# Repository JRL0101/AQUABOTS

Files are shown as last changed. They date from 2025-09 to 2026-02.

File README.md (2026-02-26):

# AQUABOTS — Team 26061

**University of Arizona ENGR 498B — Spring 2026**

Autonomous surface vehicle (ASV) swarm platform.  Three boats operate as a
coordinated swarm using ESP-NOW for inter-node communication.  The leader boat
carries a Jetson Orin Nano, Starlink Mini, and IMX219 camera; follower boats
run a Raspberry Pi + ESP32-S3.

---

## Repository layout

```
AQUABOTS/
├── firmware/          ESP32-S3 swarm logic (ESP-IDF v5.x, FreeRTOS)
│   └── main/          All C source files — see firmware/main/README.md
├── ground_station/    Jetson Orin Nano Python dashboard
│   └── README.md      Setup, config, and data-pipeline docs
├── docs/              Project documents (CDR, ISR, integration plan)
│   └── pics/          Hardware and testing photos
├── reference/         Previous team's CAD files and reference code
└── README.md          This file
```

---

## Hardware overview

| Component | Leader boat | Follower boats |
|---|---|---|
| Compute | Jetson Orin Nano | Raspberry Pi |
| Comms MCU | ESP32-S3 | ESP32-S3 |
| Connectivity | Starlink Mini | — |
| Camera | IMX219 (CSI) | — |
| Obstacle sensor | DFRobot A02YYUW ultrasonic | DFRobot A02YYUW ultrasonic |
| Battery | Ovonic 6S 6000 mAh 22.2V | — |

---

## Subsystems

### `firmware/` — ESP32-S3 swarm firmware

Written in C with ESP-IDF v5.x and FreeRTOS.  All boats run the same binary;
identity is stored in NVS flash.

Key modules:

| Module | Description |
|---|---|
| `node_config` | NVS-backed node identity (node_id 1–254) |
| `swarm_transport` | ESP-NOW send/receive, ping/ack diagnostics |
| `membership` | Peer discovery, heartbeat, active member table |
| `leader_election` | Highest-node-id election with cooldown |
| `scheduler` | TDMA slot coordination (50 ms slots) |
| `command_engine` | Command parsing, routing, and execution |
| `formation` | Line, wedge, circle, column patterns |
| `obstacle_sense` | Pluggable sensor abstraction layer |
| `a02yyuw` | DFRobot A02YYUW UART driver (9600 baud) |
| `avoidance` | State-machine collision avoidance (CLEAR/WARNING/DANGER) |

See `firmware/main/README.md` for build instructions, console commands, and
integration guide.

### `ground_station/` — Jetson Orin Nano dashboard

Python Flask app serving the operator dashboard.  Key components:

| File | Description |
|---|---|
| `app.py` | Flask server — dashboard, `/api/data`, iPerf3 test |
| `serial_bridge.py` | UART bridge: ESP32-S3 → Jetson (IF-3) |
| `mqtt_client.py` | MQTT cloud telemetry via Starlink (IF-4/IF-5) |
| `config.py` | All IPs, ports, and serial settings (env-var overrides) |
| `signaling_server.py` | WebRTC signaling server (WebSocket) |

See `ground_station/README.md` for deployment instructions and environment
variable reference.

---

## Quick start

### Firmware

```bash
cd firmware
idf.py set-target esp32s3
idf.py build
idf.py -p <PORT> flash monitor
```

Provision node identity at the serial console:
```
config set_id <1-254>
```

### Ground station

```bash
cd ground_station
pip install -r requirements.txt
export AQUABOT_SIGNALING_CLIENT_HOST=<jetson-lan-ip>
python app.py           # starts Flask + serial bridge + MQTT
python signaling_server.py   # separate terminal
```

Open `http://<jetson-ip>:5000` in a browser.

---

## Team

| Name | Role |
|---|---|
| John | ESP32-S3 swarm firmware, Power System & Integration |
| Mayra | Ground station dashboard |
| Jamie | Water quality sensors (pH, salinity, temperature) |
| Robert | Propulsion / ESC hardware |

---

## Interfaces (from Software Integration Plan)

| ID | Description | Status |
|---|---|---|
| IF-1 | ESP32-S3 ↔ Pixhawk (MAVLink UART) | Pending |
| IF-3 | ESP32-S3 ↔ Jetson (sensor UART) | Wired, driver ready |
| IF-4/5 | Jetson ↔ Cloud (MQTT via Starlink) | Client ready, broker TBD |
| IF-6 | ESP32-S3 ↔ ESP32-S3 (ESP-NOW) | Complete |

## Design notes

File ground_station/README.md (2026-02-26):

# AquaBot Ground Station

Python/JavaScript web dashboard running on the **Jetson Orin Nano** aboard the
leader boat.  Provides the operator with a live video feed, real-time sensor
readings, swarm telemetry, and network performance metrics over Starlink.

---

## Directory layout

```
ground_station/
├── app.py                 Flask web server (port 5000)
├── signaling_server.py    WebRTC signaling server (WebSocket, port 8765)
├── serial_bridge.py       UART bridge — ESP32-S3 ↔ Jetson (IF-3)
├── mqtt_client.py         MQTT cloud telemetry via Starlink (IF-4 / IF-5)
├── config.py              Centralized configuration (IPs, ports, serial)
├── requirements.txt       Python dependencies
├── static/
│   ├── css/style.css
│   └── js/
│       ├── webrtc.js      WebRTC client (video receive + zoom/record cmds)
│       ├── telemetry.js   Polls /api/data every 2 s, updates dashboard
│       ├── bandwidth.js   iPerf3 network test trigger
│       └── controls.js    (reserved)
└── templates/
    └── index.html         Operator dashboard
```

---

## Quick start

### 1 — Install dependencies

```bash
cd ground_station
pip install -r requirements.txt
```

`iperf3` must also be installed on the Jetson:
```bash
sudo apt install iperf3
```

### 2 — Set environment variables

All IPs and ports are configurable without editing code.  Set the variables
that differ from the defaults below before launching.

| Variable | Default | Description |
|---|---|---|
| `AQUABOT_SIGNALING_CLIENT_HOST` | `localhost` | Jetson LAN IP seen by the browser (e.g. `192.168.1.187`) |
| `AQUABOT_SIGNALING_HOST` | `0.0.0.0` | Address the signaling server binds to |
| `AQUABOT_SIGNALING_PORT` | `8765` | WebSocket port for signaling |
| `AQUABOT_IPERF_HOST` | `192.168.1.77` | iPerf3 server IP |
| `AQUABOT_IPERF_PORT` | `5201` | iPerf3 port |
| `AQUABOT_FLASK_HOST` | `0.0.0.0` | Flask bind address |
| `AQUABOT_FLASK_PORT` | `5000` | Flask port |
| `AQUABOT_SERIAL_PORT` | `/dev/ttyUSB0` | ESP32-S3 serial device |
| `AQUABOT_SERIAL_BAUD` | `115200` | Serial baud rate |
| `AQUABOT_MQTT_BROKER` | `broker.hivemq.com` | MQTT broker hostname |
| `AQUABOT_MQTT_PORT` | `1883` | MQTT broker port |
| `AQUABOT_MQTT_USER` | *(empty)* | MQTT username (if required) |
| `AQUABOT_MQTT_PASS` | *(empty)* | MQTT password (if required) |
| `AQUABOT_NODE_ID` | `leader` | Node identifier for MQTT topics |

Example for deployment on the Jetson:
```bash
export AQUABOT_SIGNALING_CLIENT_HOST=192.168.1.187
export AQUABOT_SERIAL_PORT=/dev/ttyUSB0
```

### 3 — Launch the Flask dashboard (starts serial bridge + MQTT automatically)

```bash
python app.py
```

Open `http://<jetson-ip>:5000` in a browser.

### 4 — Launch the WebRTC signaling server (separate terminal)

```bash
python signaling_server.py
```

The IMX219 camera stream is sent to the signaling server by a GStreamer
pipeline on the Jetson; the browser receives it via WebRTC.

---

## Interface diagram

```
ESP32-S3 (swarm node)
    │  UART 115200 baud (IF-3)
    ▼
serial_bridge.py  ──────────► shared state dict (thread-safe)
                                    │                │
                              Flask /api/data    mqtt_client.py
                                    │                │
                              telemetry.js       Starlink Mini
                              (browser, 2 s)     (IF-4 / IF-5)
                                                      │
                                               cloud MQTT broker
```

---

## Data pipeline — sensor readings

1. **Jamie's sensors** (pH, salinity, temperature) connect to the ESP32-S3.
2. The ESP32-S3 sends newline-delimited JSON over UART:
   ```json
   {"type":"sensor","node_id":1,"ph":7.2,"salinity":35.1,"temp_c":22.5}
   ```
3. `serial_bridge.py` parses the frame and updates the shared state dict.
4. `app.py /api/data` serves the state as JSON.
5. `telemetry.js` polls `/api/data` every 2 seconds and updates the DOM.

The same pipeline carries swarm telemetry and obstacle/avoidance state.

---

## MQTT topic layout

| Topic | Direction | Payload |
|---|---|---|
| `aquabots/<node_id>/sensor` | publish | pH, salinity, temp_c |
| `aquabots/<node_id>/telemetry` | publish | heading, leader_id, formation |
| `aquabots/<node_id>/obstacle` | publish | avoidance state, range |
| `aquabots/swarm/status` | publish | combined heartbeat |
| `aquabots/command/+` | subscribe | operator commands from cloud |

---

## Pending integration items

- **ESP32-S3 TX path** — `serial_bridge.py` currently only reads; outbound
  command forwarding (Jetson → ESP32-S3) will be added when IF-3 wiring is
  complete.
- **MQTT TLS** — for production, set broker to an AWS IoT Core endpoint and
  configure TLS certificates via environment variables.
- **Mayra's signaling server** currently broadcasts WebRTC to all connected
  clients.  If security is needed, add session tokens.

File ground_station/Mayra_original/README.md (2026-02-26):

# Mayra's Original Dashboard Code

This contains an exact, unmodified copy of your dashboard code.  Nothing here has been changed.

The working version of the dashboard is one level up in `ground_station/`.
That version has been extended to connect to the ESP32-S3 sensor pipeline and
the MQTT cloud uplink, but your logic, structure, and UI are untouched.

## What changed in the integrated version (ground_station/)

| File | What changed |
|---|---|
| `app.py` | Added `/api/data` endpoint; imports `config.py`, `serial_bridge.py`, `mqtt_client.py`; hardcoded IPs moved to `config.py` |
| `signaling_server.py` | Bind address/port read from `config.py` instead of hardcoded |
| `templates/index.html` | Added `id=` attributes to sensor/swarm fields so `telemetry.js` can populate them; added Swarm Status panel; loads `telemetry.js`; signaling URL injected by Flask |
| `static/js/webrtc.js` | Reads signaling server URL from `window.AQUABOT_SIGNALING_URL` (set by Flask template) instead of hardcoded `192.168.1.187` |

## New files added

| File | Purpose |
|---|---|
| `config.py` | All IPs, ports, and serial settings in one place; all overridable via environment variables |
| `serial_bridge.py` | Reads sensor/telemetry data from ESP32-S3 over UART |
| `mqtt_client.py` | Publishes telemetry to cloud via Starlink MQTT |
| `static/js/telemetry.js` | Polls `/api/data` every 2 s and updates the sensor/swarm fields in the dashboard |
| `requirements.txt` | Python dependencies |

## Files not changed at all

- `static/css/style.css`
- `static/js/bandwidth.js`
- `static/js/controls.js`

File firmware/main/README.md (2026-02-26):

# AQUABOTS — ESP32-S3 Swarm Framework

**Platform:** ESP32-S3 with ESP-IDF v5.5.x
**Protocol:** ESP-NOW (2.4 GHz, channel 1)
**Target:** 20–50 node autonomous surface vehicle swarm

---

## Table of Contents

1. [Overview](#overview)
2. [System Architecture](#system-architecture)
3. [Module Reference](#module-reference)
4. [Hardware Setup](#hardware-setup)
5. [Building and Flashing](#building-and-flashing)
6. [Node Provisioning](#node-provisioning)
7. [Console Command Reference](#console-command-reference)
8. [Integration Guide](#integration-guide)
9. [Testing and Verification](#testing-and-verification)
10. [Troubleshooting](#troubleshooting)
11. [Performance Reference](#performance-reference)

---

## Overview

AQUABOTS is a distributed swarm coordination framework for ESP32-S3 microcontrollers
targeting autonomous surface vehicles (ASVs). All coordination is done peer-to-peer
over ESP-NOW — no router, broker, or infrastructure is required.

### Capabilities

- **Zero-configuration networking** — nodes discover each other automatically via broadcast
- **Persistent identity** — each node has a unique ID stored in flash that survives power cycles
- **Distributed leader election** — highest node_id automatically becomes the swarm leader
- **Time-slotted communication** — TDMA scheduling prevents radio collisions at scale
- **Synchronized command execution** — the leader sends GOTO/HOLD/STOP/RESUME to the entire swarm
- **Formation control** — four built-in patterns (line, wedge, circle, column) with configurable spacing
- **Obstacle sensing** — pluggable sensor driver system with swarm-wide scan fusion
- **Collision avoidance** — autonomous safety zones with automatic stop and alternate-path suggestion
- **Resilient design** — automatic leader failover if the current leader goes offline

### Technology Stack

| Component | Technology |
|---|---|
| Hardware | ESP32-S3 (Xtensa dual-core @ 240 MHz) |
| Framework | ESP-IDF v5.5.x |
| RTOS | FreeRTOS |
| Radio | ESP-NOW (2.4 GHz) |
| Storage | NVS (Non-Volatile Storage) |
| Console | USB Serial/JTAG |

---

## System Architecture

```
┌──────────────────────────────────────────────────────────────┐
│                       APPLICATION LAYER                       │
├────────────────────┬─────────────────────┬───────────────────┤
│  Formation Control │   Command Engine    │ Collision Avoid   │
├────────────────────┴──────┬──────────────┴───────────────────┤
│     Leader Election       │    Obstacle Sensing + Fusion      │
├───────────────────────────┴───────────────────────────────────┤
│                  Membership Discovery                          │
├───────────────────────────────────────────────────────────────┤
│           Node Configuration (NVS identity)                   │
├───────────────────────────────────────────────────────────────┤
│              Swarm Transport (ESP-NOW)                         │
└───────────────────────────────────────────────────────────────┘
```

### Data Flow

```
Physical sensor (A02YYUW)
        │  UART 9600 baud
        ▼
   a02yyuw driver ──► obstacle_sense (local scan, 10 Hz)
                              │
                              ├──► broadcast to swarm (2 Hz, MSG_TYPE_OBSTACLE)
                              │
                              ├──► receives remote scans from peers
                              │
                              └──► avoidance (polls every 250 ms)
                                        │
                                  DANGER zone ──► CMD_STOP (leader only)
                                  CLEAR found ──► suggest alternate bearing
```

---

## Module Reference

### swarm_transport (`swarm_transport.h / .c`)

ESP-NOW radio abstraction layer. Manages peer registration, send/receive dispatch,
and supports multiple simultaneous receive callbacks via a callback table.

- **Channel:** 1 (configurable via `TRANSPORT_CHANNEL`)
- **Max peers:** 20 (configurable via `TRANSPORT_MAX_PEERS`)
- **Receive dispatch:** up to 8 callbacks registered simultaneously

---

### node_config (`node_config.h / .c`)

Persistent node identity backed by NVS flash. Provides a serial provisioning
console so a single firmware binary can be flashed to every node; each board
is then assigned its unique node_id via `set_node_id`.

- **Valid node_id range:** 1–254
- **Storage:** NVS namespace `node_cfg`, key `node_id`
- **Console commands:** `set_node_id`, `get_node_id`, `info`, `help`

---

### membership (`membership.h / .c`)

Zero-configuration peer discovery. Each provisioned node broadcasts a HELLO
packet every 2 seconds. Nodes that stop broadcasting are removed from the
member table after a 10-second timeout.

- **HELLO interval:** 2 000 ms
- **Peer timeout:** 10 000 ms
- **Max peers:** 50 (configurable via `SWARM_MAX_NODES` in `swarm_protocol.h`)
- **Message:** `MSG_TYPE_HELLO` (0x02)

---

### leader_election (`leader_election.h / .c`)

Distributed leader election by highest node_id. The elected leader generates
a TDMA slot schedule and broadcasts it in beacon packets every second. All
nodes receive the beacon and update their slot timing accordingly.

- **Election rule:** highest node_id among all known members
- **Election trigger:** every 5 seconds, or when membership changes
- **TDMA slot duration:** 50 ms per node
- **Beacon interval:** 1 000 ms
- **Message:** `MSG_TYPE_BEACON` (0x03)

**Example schedule (2 nodes, IDs 1 and 2):**
```
Slot 0 (  0– 50 ms): Node 2 (leader)
Slot 1 ( 50–100 ms): Node 1
[cycle repeats every 100 ms]
```

---

### command_engine (`command_engine.h / .c`)

Swarm command distribution. Only the leader can originate commands; followers
receive and execute them. All nodes track execution state independently.
Duplicate detection (via 32-bit command ID) prevents re-execution of
retransmitted packets.

- **Commands:** `GOTO`, `HOLD`, `STOP`, `RESUME`
- **Message:** `MSG_TYPE_COMMAND` (0x04)
- **Thread-safe:** mutex-protected state machine

| Command | Parameters | Behaviour |
|---|---|---|
| GOTO | x, y, heading | Navigate swarm to waypoint |
| HOLD | — | Maintain current position |
| STOP | — | Emergency stop (motors off) |
| RESUME | — | Resume last active command |

---

### formation (`formation.h / .c`)

Coordinated spatial formations. The leader calculates relative position offsets
for each node and broadcasts the formation plan. Each node receives its assigned
offset and applies it to the shared formation centre to obtain its world position.

New patterns can be added without modifying existing code by calling
`formation_register_pattern()` with a custom calculator function.

- **Built-in patterns:** line, wedge, circle, column
- **Default spacing:** 2 000 mm (configurable 500–10 000 mm)
- **Message:** `MSG_TYPE_FORMATION` (0x05)

| Pattern | Description |
|---|---|
| `line` | Single file, leader at front |
| `wedge` | V-shape with leader at the point |
| `circle` | Nodes evenly spaced on a ring |
| `column` | Side-by-side parallel columns |

---

### obstacle_sense (`obstacle_sense.h / .c`)

Sensor abstraction with swarm-wide scan fusion. A pluggable `sensor_driver_fn`
is called at 10 Hz to collect local detections. The local scan is broadcast at
2 Hz to all peers. Remote scans from other nodes are stored and automatically
expired after 2 seconds if not refreshed.

All query APIs (`obstacle_sense_get_closest`, `obstacle_sense_path_clear`,
`obstacle_sense_get_all_scans`) operate across both local and all current remote
scans, giving every node a unified obstacle picture of the entire swarm's field
of view.

**Mock mode** is active by default. It allows full swarm testing without any
physical sensors attached. Use `mock_add` to inject test obstacles from the
console.

- **Local scan rate:** 10 Hz (100 ms interval)
- **Broadcast rate:** 2 Hz (500 ms interval)
- **Scan timeout:** 2 000 ms
- **Max tracked nodes:** 16
- **Max detections per scan:** 16
- **Message:** `MSG_TYPE_OBSTACLE` (0x07)

**Obstacle protocol frame:**
```
Header (16 bytes):
  uint16  source_node_id
  uint8   num_detections
  uint8   sensor_id
  uint32  timestamp_ms
  uint32  scan_seq
  int16   range_max_mm
  int16   fov_deg

Per detection (8 bytes each):
  int16   range_mm
  int16   bearing_deg
  int16   velocity_mms
  uint8   confidence
  uint8   object_type
```

**Object types:**

| Value | Name | Description |
|---|---|---|
| 0 | UNKNOWN | Unclassified detection |
| 1 | STATIC | Stationary object |
| 2 | MOVING | Moving object (has velocity) |
| 3 | BOAT | Another vessel |
| 4 | SHORE | Shoreline or land mass |
| 5 | DEBRIS | Floating debris |

---

### a02yyuw (`a02yyuw.h / .c`)

UART driver for the **DFRobot A02YYUW** waterproof ultrasonic distance sensor.

The A02YYUW measures range in one fixed direction using a simple 4-byte UART
protocol. Since the sensor has no angular output, each instance is configured
with a `mounting_angle_deg` that describes which direction it faces on the hull.
Up to four sensor instances can be active simultaneously at different mounting
angles to achieve multi-directional coverage.

The driver exposes `a02yyuw_scan_driver()` which is a drop-in `sensor_driver_fn`
for `obstacle_sense_register_driver()`.

**Sensor specifications:**

| Parameter | Value |
|---|---|
| Interface | UART, 9600 baud |
| Supply voltage | 3.3 V or 5 V |
| Current draw | ~40 mA |
| Detection range | 30 mm – 4 500 mm |
| Update rate | ~10 Hz |
| Waterproof rating | IP67 |
| Angular output | None (point sensor) |

**Frame format (4 bytes):**
```
Byte 0: 0xFF        (header)
Byte 1: DATA_H      (distance high byte)
Byte 2: DATA_L      (distance low byte)
Byte 3: SUM         (checksum = (0xFF + DATA_H + DATA_L) & 0xFF)

Distance (mm) = DATA_H * 256 + DATA_L
Valid range: 30 to 4500 mm
```

**Wiring:**

| Wire colour | Connect to |
|---|---|
| Red | 3.3 V or 5 V |
| Black | GND |
| Blue | ESP32 UART RX pin (sensor TX) |
| Green | ESP32 UART TX pin (sensor RX) — usually unused |

**Multi-sensor layout for 360° coverage:**
```
            BOW (0°)
              [S0]
               ↑
               │
  [S3] (-90°)──┼──(+90°) [S1]
               │
               ↓
              [S2]
           STERN (180°)

S0: UART_NUM_1, RX=GPIO17, angle=   0° (bow)
S1: UART_NUM_2, RX=GPIO18, angle= +90° (starboard)
S2: requires additional UART,  angle= 180° (stern)
S3: requires additional UART,  angle= -90° (port)
```

**Activating the hardware driver:**

In `main.c`, uncomment the sensor block before `obstacle_sense_start()`:

```c
#include "a02yyuw.h"

// Initialize sensors (call before obstacle_sense_start)
a02yyuw_init(0, UART_NUM_1, GPIO_NUM_17, -1, 0);   // Bow sensor
a02yyuw_init(1, UART_NUM_2, GPIO_NUM_18, -1, 90);  // Starboard sensor

// Register with obstacle_sense (replaces mock driver)
obstacle_sense_register_driver(a02yyuw_scan_driver);
obstacle_sense_configure(4500, 120);  // 4.5 m range, 120° FOV per sensor
```

---

### avoidance (`avoidance.h / .c`)

Collision avoidance policy engine. Runs a 250 ms check loop that queries the
fused obstacle picture from `obstacle_sense` and transitions through a three-level
state machine:

```
DISABLED → CLEAR → WARNING → DANGER
               ↑_______________|
```

| State | Condition | Action |
|---|---|---|
| CLEAR | No obstacle within `warning_mm` | None |
| WARNING | Obstacle < `warning_mm` | Fire state callback; log alert |
| DANGER | Obstacle < `danger_mm` | Fire callback; auto-stop (leader); suggest alternate bearing |

When entering DANGER, the engine searches 8 candidate bearings
(0°, ±45°, ±90°, ±135°, 180°) for the first one that is clear within
`warning_mm`. The result is reported via the `avoidance_suggest_cb_t` callback.

Auto-stop only executes when `auto_stop = true` **and** this node is the swarm
leader, keeping the entire swarm synchronized rather than having individual nodes
act independently.

**Default thresholds:**

| Parameter | Default | Description |
|---|---|---|
| `danger_mm` | 500 mm | Obstacle closer than this triggers DANGER |
| `warning_mm` | 1 500 mm | Obstacle closer than this triggers WARNING |
| `corridor_deg` | 40° | Path-check corridor total width (±20°) |
| `auto_stop` | true | Issue CMD_STOP when entering DANGER |

---

## Hardware Setup

### Minimum (mock sensor mode)

- 2× ESP32-S3 development boards
- USB cables for serial console and flashing

No physical distance sensors are required. The mock driver in `obstacle_sense`
lets you simulate obstacles via console commands for full swarm testing.

### With A02YYUW Sensors

**Single forward-facing sensor:**

```
ESP32-S3                  A02YYUW
──────────                ───────
3.3V or 5V ──────────────  Red
GND        ──────────────  Black
GPIO17 (RX)──────────────  Blue (sensor TX)
(TX unused)
```

**Dual sensor (bow + starboard):**

```
ESP32-S3     Sensor 0 (bow)   Sensor 1 (starboard)
3.3V     ──► Red              Red
GND      ──► Black            Black
GPIO17   ──► Blue             —
GPIO18   ──────────────────►  Blue
```

> **Note:** The ESP32-S3 has three hardware UART peripherals (UART0, UART1, UART2).
> UART0 is normally used by the serial console, leaving UART1 and UART2 for sensors.
> For more than two sensors, consider an external UART multiplexer.

---

## Building and Flashing

### Prerequisites

- ESP-IDF v5.5.x ([installation guide](https://docs.espressif.com/projects/esp-idf/en/latest/esp32s3/get-started/))
- Two or more ESP32-S3 development boards
- USB cables

### Build

```bash
cd swarmLogic

# Build firmware (single binary for all nodes)
idf.py build
```

### Flash

```bash
# Flash Node 1 (adjust COM port as needed)
idf.py -p COM9 flash monitor

# In the serial console:
swarm> set_node_id 1
# Press Ctrl+T, Ctrl+R to restart

# Flash Node 2
idf.py -p COM7 flash monitor

swarm> set_node_id 2
# Press Ctrl+T, Ctrl+R to restart
```

### Expected Boot Output

```
I (442) MAIN: ================================================
I (442) MAIN:  AQUABOTS — ESP32-S3 Swarm Framework
I (442) MAIN: ================================================
I (442) MAIN: Node ID : 2
I (442) MAIN: MAC     : 10:b4:1d:d0:a5:f4
I (452) MEMBERSHIP: HELLO broadcast task started
I (452) LEADER_ELECTION: Leader election task started
I (452) COMMAND_ENGINE: Command engine started
I (452) FORMATION: Formation control started
I (452) OBSTACLE_SENSE: Scan task started (interval=100 ms)
I (452) OBSTACLE_SENSE: Broadcast task started (interval=500 ms)
I (452) AVOIDANCE: Avoidance started
I (1052) MAIN: *** NEW MEMBER DISCOVERED ***
I (1052) MAIN:     Node ID: 1
I (1072) MAIN: *** NEW LEADER ELECTED ***
I (1072) MAIN:     Leader Node ID: 2
```

---

## Node Provisioning

Each board must be assigned a unique node_id before it can participate in the
swarm. Node IDs persist through firmware updates and power cycles.

```bash
# Check current node_id
swarm> get_node_id

# Assign a node_id (1–254)
swarm> set_node_id 3

# Restart to activate
[Ctrl+T, Ctrl+R]

# Verify
swarm> info
```

**Rules:**
- Valid range: 1–254
- Higher node_id = leader (deterministic, no election messages needed)
- Each node in the swarm must have a unique ID
- ID 0 and 255 are reserved

---

## Console Command Reference

### Node and Network Status

| Command | Description |
|---|---|
| `help` | List all available commands |
| `info` | Show node_id, MAC, and provisioning status |
| `get_node_id` | Display current node_id |
| `set_node_id <id>` | Assign node_id 1–254 (requires restart) |
| `members` | Show discovered swarm members with RSSI |
| `leader` | Show current leader and election state |
| `schedule` | Show TDMA slot schedule |
| `status` | Show current command execution state |

### Swarm Commands *(leader only)*

| Command | Description | Example |
|---|---|---|
| `goto <x> <y> [heading]` | Navigate swarm to waypoint (metres) | `goto 10 20 90` |
| `hold` | Hold current position | `hold` |
| `stop` | Emergency stop (motors off) | `stop` |
| `resume` | Resume last command | `resume` |

### Formation Control *(leader only)*

| Command | Description | Example |
|---|---|---|
| `formation <type>` | Set formation pattern | `formation wedge` |
| `spacing <mm>` | Set inter-node spacing in mm | `spacing 3000` |
| `fmove <dx> <dy>` | Translate entire formation (mm) | `fmove 1000 500` |
| `fstatus` | Show formation type and node assignments | `fstatus` |

Formation types: `line` `wedge` `circle` `column`

### Obstacle Sensing

| Command | Description | Example |
|---|---|---|
| `sensors` | Show sensor driver status and scan counters | `sensors` |
| `detections` | Show all local and remote obstacle detections | `detections` |
| `mock_add <range_mm> <bearing_deg>` | Inject a mock obstacle | `mock_add 2000 0` |
| `mock_clear` | Remove all mock obstacles | `mock_clear` |
| `path_check <bearing> [corridor] [range]` | Check if a heading is clear | `path_check 0` |

`path_check` defaults: corridor = 30°, range = 3 000 mm

### Collision Avoidance

| Command | Description | Example |
|---|---|---|
| `avoid_status` | Show avoidance state and current thresholds | `avoid_status` |
| `avoid_enable` | Enable the avoidance engine | `avoid_enable` |
| `avoid_disable` | Disable the avoidance engine | `avoid_disable` |
| `avoid_config <param> <value>` | Tune a threshold at runtime | `avoid_config danger_mm 400` |

`avoid_config` parameters: `danger_mm` `warning_mm` `corridor_deg` `auto_stop`

---

## Integration Guide

### Registering a Real Sensor

To replace mock mode with the A02YYUW hardware driver, add the following block
to `main.c` **before** the call to `obstacle_sense_start()`:

```c
#include "a02yyuw.h"

// One sensor, facing forward (0°), on UART1, RX = GPIO17
a02yyuw_init(0, UART_NUM_1, GPIO_NUM_17, -1, 0);

// Replace mock driver with the hardware driver
obstacle_sense_register_driver(a02yyuw_scan_driver);

// Optional: match sensor spec (4.5 m range, 120° FOV)
obstacle_sense_configure(4500, 120);
```

### Implementing a Custom Sensor Driver

Any sensor that can produce range/bearing measurements can be used. Implement
the `sensor_driver_fn` signature and register it:

```c
bool my_sensor_driver(obstacle_scan_t *scan)
{
    // Read from hardware
    int16_t range_mm = my_sensor_read();
    if (range_mm <= 0) {
        scan->num_detections = 0;
        return true;  // Empty scan is valid
    }

    scan->num_detections = 1;
    scan->detections[0].range_mm     = range_mm;
    scan->detections[0].bearing_deg  = 0;      // Sensor faces forward
    scan->detections[0].velocity_mms = 0;
    scan->detections[0].confidence   = 85;
    scan->detections[0].object_type  = OBSTACLE_TYPE_UNKNOWN;
    return true;
}

// Register before obstacle_sense_start()
obstacle_sense_register_driver(my_sensor_driver);
```

### Adding a Formation Pattern

```c
// 1. Add enum value in formation.h
typedef enum {
    FORMATION_NONE = 0,
    FORMATION_LINE,
    FORMATION_WEDGE,
    FORMATION_CIRCLE,
    FORMATION_COLUMN,
    FORMATION_DIAMOND,   // ← new pattern
    FORMATION_COUNT
} formation_type_t;

// 2. Implement calculator function
bool diamond_calc(int node_index, int total_nodes,
                  int32_t spacing_mm, formation_position_t *pos)
{
    // Assign positions for diamond arrangement
    // ...
    return true;
}

// 3. Register in formation_init() inside formation.c
formation_register_pattern(FORMATION_DIAMOND, "diamond", diamond_calc);
```

### Avoidance Callbacks

```c
void my_state_cb(avoidance_state_t state, const obstacle_detection_t *closest)
{
    if (state == AVOIDANCE_STATE_DANGER && closest) {
        // Log to mission computer, light warning LED, etc.
    }
}

void my_suggest_cb(int16_t bearing_deg, int16_t range_clear_mm)
{
    // Could feed this bearing into a higher-level autopilot
    printf("Suggested heading: %d°\n", bearing_deg);
}

// Register before avoidance_start()
avoidance_register_state_cb(my_state_cb);
avoidance_register_suggest_cb(my_suggest_cb);
```

---

## Testing and Verification

### Basic Connectivity

```bash
# On both nodes
swarm> info
# Should show provisioned node_id and MAC

swarm> members
# Should show 1 peer after ~2 seconds
```

### Leader Election

```bash
# On both nodes
swarm> leader
# Node with higher node_id should show "I am leader: YES"
# Lower node_id shows "I am leader: NO"
```

### Command Distribution

```bash
# On the LEADER node only
swarm> goto 100 200 90
# Both nodes should log "*** COMMAND RECEIVED ***"

swarm> status
# Both nodes should show "Command: GOTO, Status: EXECUTING"
```

### Formation Control

```bash
# On the LEADER node
swarm> formation line
# Both nodes should log "*** FORMATION CHANGED ***" and "*** POSITION ASSIGNED ***"

swarm> fstatus
# Shows current formation type and each node's assigned offset
```

### Obstacle Sensing

```bash
# On any node
swarm> sensors
# Should show: Running: YES, Mock mode: ENABLED

# Add mock obstacles
swarm> mock_add 2000 0      # 2 m straight ahead
swarm> mock_add 1500 45     # 1.5 m at 45°
swarm> mock_add 3000 -30    # 3 m at -30°

# Verify local detections
swarm> detections
# Shows 3 obstacles with range/bearing/type

# On the OTHER node — verify remote reception
swarm> detections
# Shows obstacles from the first node as "(remote)"

# Test path clearance
swarm> path_check 0
# Expected: "BLOCKED" (obstacle at 2000 mm @ 0°)

swarm> path_check 90
# Expected: "CLEAR" (no obstacles near 90°)

# Clean up
swarm> mock_clear
swarm> detections
# Expected: no detections
```

### Collision Avoidance

```bash
swarm> avoid_status
# Shows: State: CLEAR, thresholds, auto-stop setting

# Trigger a danger condition with a mock obstacle
swarm> mock_add 400 0       # 40 cm directly ahead (< 500 mm danger zone)

# Watch logs for:
# W AVOIDANCE: DANGER: 400 mm @ 0° (node X)
# W AVOIDANCE: Auto-stop issued to swarm
# I AVOIDANCE: Suggested alternate bearing: 90°

# Adjust thresholds at runtime
swarm> avoid_config danger_mm 300
swarm> avoid_config auto_stop 0     # Disable auto-stop

# Clean up
swarm> mock_clear
```

---

## Troubleshooting

### Nodes Don't Discover Each Other

1. Verify both nodes are provisioned: `get_node_id` (must return 1–254)
2. Both must be restarted after provisioning
3. Check "HELLO broadcast task started" appears in boot log
4. Verify distance < 30 m (indoor range is typically 10–50 m)
5. Check RSSI in `members` output — values worse than −80 dBm indicate weak signal

### No Leader Elected

1. Wait 5 seconds — leader election runs on a fixed interval
2. Verify both nodes appear in each other's `members` table
3. Confirm both nodes have different node_ids

### Command "Failed: ESP_ERR_INVALID_STATE"

Only the leader can originate commands. Run `leader` to find which node is
the leader, and issue commands from that node.

### Scan Count Stays at 0 in `sensors`

`obstacle_sense_start()` requires a valid node_id. If the node was not
provisioned at boot time, restart after provisioning.

### Remote Obstacles Not Appearing

1. Confirm both nodes are discovered (`members`)
2. Check that the remote node's scan count is incrementing (`sensors`)
3. Look for `*** REMOTE SCAN from node X ***` in the log
4. Remote scans expire after 2 seconds if broadcasts stop

### `path_check` Always Returns CLEAR

Add mock obstacles first (`mock_add 1000 0`). Confirm `detections` shows
them before running `path_check`. The default check range is 3 000 mm —
obstacles beyond that range will not block the path.

### A02YYUW Sensor Not Responding

1. Verify wiring: blue (sensor TX) → ESP32 UART RX pin
2. Confirm correct UART port and GPIO pin numbers in `a02yyuw_init()`
3. Check that no other peripheral shares the same UART port
4. Run `sensors` to confirm the driver is registered and not in mock mode
5. A stale reading appears in `a02yyuw_print_status()` if no valid frame
   has been received within 500 ms — verify sensor power (needs 3.3V or 5V)

---

## Performance Reference

### Network Timings

| Metric | Value |
|---|---|
| Ping round-trip time | 4–5 ms |
| RSSI at 1 m | −15 to −25 dBm |
| Peer discovery time | 0–4 seconds |
| Leader election time | < 5 seconds |
| HELLO broadcast interval | 2 000 ms |
| Beacon interval | 1 000 ms |
| TDMA slot duration | 50 ms/node |
| Command latency | < 50 ms |
| Obstacle scan rate (local) | 100 ms (10 Hz) |
| Obstacle broadcast rate | 500 ms (2 Hz) |
| Obstacle scan expiry | 2 000 ms |
| Avoidance check interval | 250 ms |

### Resource Usage (Per Node)

| Resource | Usage |
|---|---|
| Flash (firmware) | ~870 KB |
| RAM (all modules) | ~16 KB |
| CPU | < 10% (all tasks combined) |
| Network traffic | ~150–200 bytes/sec |

### Scalability

| Swarm size | TDMA cycle | Network traffic |
|---|---|---|
| 2 nodes | 100 ms | ~100 bytes/sec |
| 10 nodes | 500 ms | ~300 bytes/sec |
| 50 nodes | 2 500 ms | ~800 bytes/sec |

Maximum supported swarm size: **50 nodes** (set by `SWARM_MAX_NODES` in
`swarm_protocol.h` and `FORMATION_MAX_NODES` implied by formation arrays).

### RSSI Signal Quality Guide

```
−10 to −30 dBm  → Excellent  (< 1 metre)
−30 to −50 dBm  → Good       (1–10 metres)
−50 to −70 dBm  → Fair       (10–50 metres)
−70 to −90 dBm  → Weak       (50–100 metres, marginal)
```

---

## File Structure

```
main/
├── main.c                  Entry point; module init, callbacks, console setup
├── swarm_protocol.h        Packet format definitions and message type enum
├── swarm_transport.h / .c  ESP-NOW transport abstraction
├── node_config.h / .c      Persistent node identity (NVS) and serial console
├── membership.h / .c       Peer discovery via HELLO/BEACON broadcasts
├── leader_election.h / .c  Leader election and TDMA schedule distribution
├── scheduler.h / .c        TDMA slot scheduling utilities
├── command_engine.h / .c   Swarm command distribution and execution
├── formation.h / .c        Formation control with pluggable pattern system
├── obstacle_sense.h / .c   Sensor abstraction and swarm-wide scan fusion
├── a02yyuw.h / .c          DFRobot A02YYUW ultrasonic sensor UART driver
├── avoidance.h / .c        Collision avoidance policy engine
└── CMakeLists.txt          ESP-IDF component build configuration
```

---

## Hardware Compatibility

| Board | Status |
|---|---|
| ESP32-S3 | ✅ Primary target, fully tested |
| ESP32 (original) | ✅ Should work (untested) |
| ESP32-C3 | ✅ Should work (untested) |
| ESP32-S2 | ✅ Should work (untested) |
| ESP32-C6 | ⚠️ Requires WiFi driver changes |
| ESP32-H2 | ❌ No WiFi radio |

---

## License

- **ESP-IDF:** Apache 2.0 (Espressif Systems)
- **ESP-NOW:** Proprietary (Espressif Systems)
- **FreeRTOS:** MIT

---

*AQUABOTS Swarm Framework — ESP32-S3 Edition*
*Platform: ESP32-S3 with ESP-IDF v5.5.x*
*Last updated: February 2026*

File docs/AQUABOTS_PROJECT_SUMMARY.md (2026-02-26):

# AQUABOTS PROJECT — COMPREHENSIVE SUMMARY
## Communications & Power Systems (For Claude Code Context)

**Project:** AQUABOTS Aeropak — Autonomous Underwater/Surface Swarm Drones
**Course:** ENGR 498B Spring 2026, University of Arizona (Team 26061)
**Role:** John — Software Integration Lead (Communications + Power)
**Last Updated:** February 25, 2026

---

## TEAM STRUCTURE

- **John** — Software Integration Lead: Swarm communications (ESP32-S3 / ESP-NOW), power system design
- **Jamie** — Sensors & Data Acquisition: pH, salinity, temperature, camera (IMX219)
- **Mayra** — GUI / Ground Station & Starlink Communication
- **Robert** — Propulsion & Flight Control: Pixhawk modules, motor/servo

---

## PROJECT OVERVIEW

AQUABOTS is a swarm of autonomous surface drones for environmental monitoring. Each drone carries sensors (pH, salinity, temperature), a camera, and communicates via ESP-NOW for local swarm coordination and Starlink for cloud/ground station uplink. The system uses a leader-follower architecture where the leader drone has a Starlink uplink and relays commands/data to follower drones via ESP-NOW mesh.

---

## 1. COMMUNICATIONS SYSTEM

### 1.1 Architecture

The communication system has **6 integration interfaces across 4 subsystems**:

| Interface | Connection | Protocol | Status |
|---|---|---|---|
| IF-1 | ESP32 ↔ Pixhawk | UART / MAVLink | Spec Week 8 |
| IF-2 | Sensors → ESP32 | I2C / ADC | Spec Week 8 |
| IF-3 | ESP32 ↔ Jetson | UART / Serial (115200) | Spec Week 8 |
| IF-4 | Drone ↔ Cloud | Starlink / MQTT | Spec Week 8 |
| IF-5 | Cloud ↔ Ground Station | MQTT + WebSocket | Spec Week 8 |
| IF-6 | Drone ↔ Drone | ESP-NOW | ✅ DONE |

### 1.2 Swarm Communication — ESP-NOW (IF-6)

**Platform:** ESP32-S3 (Xtensa dual-core @ 240 MHz)
**Framework:** ESP-IDF v5.5.x
**Protocol:** ESP-NOW (IEEE 802.11 Action Frames, Layer 2 MAC, connectionless)
**RTOS:** FreeRTOS
**Language:** C (embedded systems)

#### 9-Step Development Roadmap — Current Status: 6/9 Complete (67%)

**STEP 1: Modular Scaffolding ✅ COMPLETE**
- 9-module architecture, 20-file modular design
- ESP-NOW transport layer (2.4 GHz, 250 kbps)
- Packed binary struct packets (64 bytes) — 10x smaller than JSON
- Verified: RTT 4-5ms, RSSI -15 to -30 dBm, 0% packet loss
- Source files: `swarm_transport.c/h`

**STEP 2: NVS Node Provisioning ✅ COMPLETE**
- Persistent node identity in NVS flash (survives power cycles)
- Single firmware binary for all nodes, runtime node_id assignment (1-254)
- Console commands: `set_node_id`, `get_node_id`, `info`, `help`
- Source files: `node_config.c/h`

**STEP 3: Membership Discovery ✅ COMPLETE**
- HELLO broadcast protocol (2-second interval)
- Automatic peer discovery (no hardcoded MACs — zero-configuration)
- Dynamic member table (50 node capacity)
- Timeout detection (10 seconds), join/leave callbacks
- Verified: Discovery time 2-4 seconds, RSSI tracking -16 to -24 dBm
- Source files: `membership.c/h`

**STEP 4: Leader Election + TDMA ✅ COMPLETE**
- Distributed leader election (highest node_id wins)
- TDMA beacon broadcasts (1-second interval), 50ms time slots per node
- Automatic schedule generation, leader failover within 2-7 seconds
- Console commands: `leader`, `schedule`
- Source files: `leader_election.c/h`

**STEP 5: Command Engine ✅ COMPLETE**
- Command types: GOTO, HOLD, STOP, RESUME
- Thread-safe execution (mutex protection)
- Duplicate command detection, real-time status tracking
- Leader-only command sending enforced
- Verified: <50ms command latency, 100% success rate
- Console commands: `goto <x> <y> [heading]`, `hold`, `stop`, `resume`, `status`
- Source files: `command_engine.c/h`

**STEP 6: Formation Control ✅ COMPLETE (Verified Feb 09, 2026)**
- Four formation patterns: LINE, CHEVRON (wedge), CIRCLE, INDIVIDUAL
- Leader sets formation type + spacing, config broadcast via ESP-NOW
- Each node calculates own position from index (extensible function pointer pattern)
- Hardware verified test results:
  - LINE 2000mm: Leader (0,0), Follower (0,-2000) → PASS
  - WEDGE 2000mm: Leader (0,0), Follower (-1000,-2000) → PASS
  - WEDGE 500mm: Leader (0,0), Follower (-250,-500) → PASS
  - Spacing change: Scaled correctly → PASS
  - Non-leader command rejection: → PASS
- Console commands: `formation <type>`, `spacing <mm>`, `fmove <x> <y>`, `fstatus`

**STEP 7: Obstacle Sensor Scaffolding — PLANNED**
- Sensor interface abstraction layer
- Mock obstacle data API for testing
- Estimated ~300 lines code

**STEP 8: Ultrasonic Distance Sensor Integration — PLANNED**
- Real sensor driver, object detection
- Originally planned as mmWave radar, may use ultrasonic
- Estimated ~400 lines code

**STEP 9: Avoidance Policy — PLANNED**
- Collision avoidance algorithms, dynamic path planning
- Detection range target: 3m minimum, response time <500ms
- Estimated ~200 lines code

**FINAL STEP (after 9): Debugging and Stress Testing**

### 1.3 Swarm Architecture Details

**Topology:** Hybrid Star-Mesh ("Gateway & Swarm")
- Main Drone (Gateway): Starlink uplink + ESP-NOW Rx/Tx + Jetson Nano + ESP32
- Follower Drones (Swarm): ESP-NOW only (relays to main), sensors, Raspberry Pi + ESP32

**Routing:** Custom flooding algorithm with TTL=3 for multi-hop relay when direct LOS blocked

**Control Strategy:** "Virtual Rigid Body"
- Swarm treats leader as origin (0,0), moves as single fixed coordinate frame
- Follower derives target using leader's heading rotation matrix + offset vector
- PID controller drives motor thrust to zero distance error
- Failsafe: If data age > 3.0s → "Station Keep" (hold GPS position)

### 1.4 Performance Metrics (Verified)

| Metric | Spec | Achieved | Status |
|---|---|---|---|
| Communication Range | 30m indoor | 30m+ (designed) | ✅ PASS |
| Discovery Time | <5 seconds | 2-4 seconds | ✅ PASS |
| Command Latency | <100ms | <50ms | ✅ PASS |
| RTT Latency | — | <5ms | ✅ PASS |
| RSSI | >-70 dBm | -16 to -24 dBm | ✅ PASS |
| Packet Loss | <5% | 0% | ✅ PASS |
| Max Swarm Size | 20-50 nodes | 50 (designed, tested 2) | ✅ PASS |
| Leader Election Time | <10 seconds | 5 seconds | ✅ PASS |
| TDMA Slot Duration | 50ms | 50ms | ✅ PASS |
| Throughput | — | 50 packets/sec | ✅ PASS |

### 1.5 Bandwidth Analysis

| Link | Available | Required | Margin |
|---|---|---|---|
| Swarm (ESP-NOW) | ~1,000 kbps | 10 kbps (2 drones) | 99% free |
| Satellite (Starlink) | ~5,000 kbps | 2,560 kbps (video+telemetry) | ~50% free |

### 1.6 Starlink Communication

- Starlink Mini unit (antenna + router in one)
- Direct power from 22.2V battery rail (Starlink Mini accepts 12-48V DC input)
- Ethernet connection to Jetson Orin Nano (100BASE-T, Cat5e, RJ-45)
- Worst-case tested speeds: Uplink 10 Mbps, Downlink 55 Mbps (tested in high Wi-Fi interference neighborhood)
- CDE-1 validated: Reliable two-way communication via Starlink uplink and GUI dashboard
- Video uplink: WebRTC
- Telemetry: MQTT

### 1.7 Code Quality

- Total production code: ~2,350 lines
- Modules complete: 6/9 (67%)
- Thread-safe: Yes (mutex protection throughout)
- Memory leaks: None detected
- Documentation: 767-line comprehensive README

---

## 2. POWER SYSTEM

### 2.1 Design Evolution (PDR → CDR → ISR)

**Original PDR Design (deprecated):**
- 24V LiFePO4 battery
- 48V boost converter + PoE injector to power Starlink
- 19V buck converter
- BMS (Battery Management System)
- Complex power chain

**CDR Design (major simplification):**
- Switched to 6S LiPo battery (22.2V, 6000mAh, 133.2 Wh)
- Eliminated 48V boost converter and PoE injector entirely
- Starlink Mini powered directly from 22.2V rail (accepts 12-48V)
- Eliminated BMS (LiPo doesn't need external BMS like LiFePO4)
- Simpler, lighter, more reliable

**ISR Design (current — fuse protection upgrades):**
- Core architecture unchanged from CDR
- Main fuse upgraded: 80A → 150A (MRBF fuse holder)
- Added dedicated 125A motor fuse (MIDI fuse block)
- Proper fuse blocks: MRBF + MIDI + ST Blade ATO
- Added thermal pads for heat management
- All parts ordered and awaiting delivery

**Post-ISR Update (judge recommendation):**
- Wiring upgraded to 12 AWG (from 14 AWG) for main power runs per ISR judge recommendation

### 2.2 Current Power Architecture (ISR)

**Battery:** Ovonic 6S LiPo, 22.2V nominal, 6000mAh, 133.2 Wh, 120C (720A) discharge limit
**Main Bus:** (+) Busbar → 22.2V Rail → (-) Busbar
**Safety:** MRBF 150A main fuse → Manual kill switch

**Power Distribution:**

| Load | Fuse | Wire Gauge | Voltage | Max Current | Cruise Power |
|---|---|---|---|---|---|
| ESC → Motor (Apisqueen 5080) | MIDI 125A | 12 AWG (upgraded from 8/10 AWG on ISR slides) | 22.2V direct | 54A max | 60W |
| Starlink Mini | ATO 7.5A slow-blow | 16 AWG | 22V direct | 2.7A | 70W |
| 5V Power Module → Pixhawk 4X FC | ATO 1A slow-blow | 18 AWG | 5V | — | — |
| 12V Buck → Jetson Orin Nano + Fan | ATO 7.5A slow-blow | 18 AWG | 12V | 1.3A | 15W |
| 5V Buck → ESP32 | ATO 1A slow-blow | 18 AWG | 5V | — | 5W |
| BEC (Castle) → Rudder Servo | ATO 2A slow-blow | 18 AWG | 7.4V | 1.0A | 5W |
| Sensors (GPS, IMU, Env) | via 3.3V reg | — | 3.3V | 0.3A | 5W |

**Battery → Kill Switch → Busbar trunk:** 4 AWG (Red+/Blk-)

### 2.3 Power Budget Summary

| Subsystem | Max Power | Cruise Power | Max Current |
|---|---|---|---|
| Propulsion (motor) | 1200W | 60W | 54A |
| Comms (Starlink) | 105W | 70W | 4.7A |
| Compute (Jetson + Fan) | 28W | 15W | 1.3A |
| Control (ESP32 + Servo) | 22W | 5W | 1.0A |
| Payload (Sensors) | 6W | 5W | 0.3A |
| **TOTAL** | **~1361W** | **~155W** | **~61.3A** |

**Cruise Endurance:** 133.2 Wh / 155W ≈ **51 minutes**
**Safety Margin:** Max draw 61.3A is well within 150A main fuse and 720A battery discharge limit

### 2.4 Signal & Data Interconnects

| Connection | Protocol | Signal | Cable | Connector |
|---|---|---|---|---|
| ESP32 → Pixhawk (IF-1) | MAVLink / UART1 | TX/RX 3.3V | 22 AWG | JST-SH 4-pin |
| ESP32 → Jetson (IF-3) | UART2 115200 | TX/RX 3.3V | 22 AWG | JST-SH 4-pin |
| ESP32 → ESC (PWM) | PWM 50Hz | 3.3V logic | 22 AWG | Servo 3-pin |
| Jetson → Camera (CSI) | MIPI CSI-2 | LVDS diff | Ribbon | 15-pin FPC |
| Jetson → Starlink | Ethernet | 100BASE-T | Cat5e | RJ-45 |

### 2.5 Parts Procurement (All Ordered as of ISR)

| Part | Qty | Price | Status |
|---|-----|---|---|
| 6S LiPo Battery | 1 | $66 | ORDERED |
| MRBF Fuse Holder | 1 | $25 | ORDERED |
| MIDI Fuse Block | 1 | $38 | ORDERED |
| ST Blade Fuse Block | 1 | $47 | ORDERED |
| 150A Fuse | 1 | $18 | ORDERED |
| 125A Fuse | 1 | $12 | ORDERED |
| Bus Bars (+/-) | 2 | $100 | ORDERED |
| Manual Kill Switch | 1 | $25 | ORDERED |
| Castle BEC (7.4V) | 1 | $47 | ORDERED |
| Thermal Pads + ATO Fuses + DC Pigtails | — | $39 | ORDERED |
| **Total** | | **$417** | |

---

## 3. SOFTWARE INTEGRATION FRAMEWORK

### 3.1 Overall Status: 5/14 major items complete (35%)

### 3.2 Five-Phase Integration Roadmap

**PHASE 1: Communications Layer ✅ COMPLETE**
- 1.1 ESP-NOW Transport Layer ✅
- 1.2 Node Identity Management ✅
- 1.3 Swarm Discovery Protocol ✅
- 1.4 Leader Election & TDMA ✅
- 1.5 Command Distribution ✅

**PHASE 2: Motion Control Integration 🟡 IN PROGRESS**
- 2.1 Propulsion Interface Layer 🔲 (motor control API, PWM, thruster mapping)
- 2.2 Navigation Controller 🔲 (waypoint nav, path planning, heading control)
- 2.3 HOLD Position Controller 🔲 (station-keeping, drift compensation)

**PHASE 3: Formation Control 🔲 PLANNED**
- 3.1 Formation Algorithm 🔲 (line, wedge, circle, column implementation)
- 3.2 Formation Maintenance 🔲 (error correction, stability, dropout handling)

**PHASE 4: Obstacle Avoidance 🔲 PLANNED**
- 4.1 Sensor Interface 🔲 (sensor driver, mock data)
- 4.2 Collision Avoidance 🔲 (detection, path replanning)

**PHASE 5: System Integration & Testing 🔲 PLANNED**
- 5.1 Hardware Integration Testing 🔲
- 5.2 Performance Validation 🔲

### 3.3 Integration Schedule

| Week | Task | Status |
|---|---|---|
| 1-2 | ESP-NOW transport layer | ✅ Complete |
| 3 | Node provisioning | ✅ Complete |
| 4-5 | Membership discovery | ✅ Complete |
| 6-7 | Leader election + TDMA | ✅ Complete |
| 8 | Command engine | ✅ Complete |
| 9-10 | Propulsion interface layer | 🟡 Current |
| 11-12 | Navigation controller | 🔲 Upcoming |
| 13-14 | Formation algorithms | 🔲 Upcoming |
| 15-16 | Sensor integration | 🔲 Upcoming |
| 17-18 | Collision avoidance | 🔲 Upcoming |
| 19-20 | Full system integration testing | 🔲 Upcoming |

### 3.4 Critical Path

Communications ✅ → Propulsion 🔴 → Navigation → Formation → Avoidance → System Test

**Current Blocker:** Propulsion hardware integration (waiting on thruster mounting & ESC setup from Robert)
**Mitigation:** Can develop navigation algorithms with mock propulsion data

---

## 4. REQUIREMENTS VERIFICATION (SRVM)

### 4.1 Communications Requirements

| Requirement | Method | Status | Evidence |
|---|---|---|---|
| 4.4.2 Inter-Drone Comms | TEST | ✅ PASS | RTT <5ms, 0% packet loss |
| 4.4.2 Inter-Drone Comms | DEMONSTRATION | ✅ PASS | Auto-discovery, synchronized commands |
| 4.4.2 Inter-Drone Comms | ANALYSIS | 🟡 In Progress | Scalability modeling (Wk 9) |
| 4.4.2 Inter-Drone Comms | INSPECTION | 🔲 Planned | Hardware/antenna check (Wk 12) |
| 5.4.2 Inter-Drone Comms | — | ✅ ESP-NOW verified | Validate 100m range at pool test |
| 5.3.1 Survivability | TEST | 🟡 Partial | Comms pass (0% loss calm), stormy test Wk 9 |
| 5.4.3 Data Relay | DEMO | 🟡 Partial | Position data OK, sensor pipeline pending Wk 11 |
| 4.4.1 Autonomy & Control | DEMO | 🟡 Partial | Commands OK, formation control done (Step 6) |
| 5.4.6 Swarm Control | — | 🟡 Partial | ESP-NOW done, need ESP32→Jetson bridge + MQTT Wk 12 |
| 4.1.2 Swarm Control | DEMO | ✅ PASS | Leader election, coordinated execution |

---

## 5. KEY DESIGN DECISIONS & CHANGES THROUGHOUT PROJECT

1. **Power simplification (PDR→CDR):** Eliminated 48V boost converter and PoE injector for Starlink. Discovered Starlink Mini accepts 12-48V DC directly, so the 22.2V LiPo can power it without conversion. Major reduction in complexity, weight, cost, and failure points.

2. **Battery change (PDR→CDR):** Switched from 24V LiFePO4 with BMS to 6S LiPo (22.2V). LiPo offers better energy density for marine application.

3. **Camera change (PDR→CDR):** Replaced GoPro Hero 7 Black with IMX219 — lower power, lower latency, CSI interface to Jetson.

4. **Fuse upgrades (CDR→ISR):** Main fuse 80A→150A (MRBF), added dedicated 125A motor fuse (MIDI), proper fuse blocks, thermal management.

5. **Wiring upgrade (post-ISR):** Upgraded main power wiring from 14 AWG to 12 AWG per ISR judge recommendation.

6. **Follower drone simplification (CDR):** Follower drones use Raspberry Pi + ESP32 (no Starlink, no Jetson). Only the main/gateway drone has Starlink uplink.

7. **Obstacle sensor decision pending:** Originally planned mmWave radar (Step 8), may use ultrasonic distance sensor instead. Decision still open.

---

## 6. DELIVERABLES TIMELINE

| Deliverable | Date | Description |
|---|---|---|
| Integrated Sensor Suite | 12/2/2025 | pH, temp, salinity sensors |
| Mounted Cameras | 12/2/2025 | IMX219 with storage/streaming |
| Communication Module | 1/22/2026 | Starlink integrated with all components & GS |
| Propulsion System | 2/19/2026 | Functional propulsion w/ motor control |
| Operational Ground Station | 3/3/2026 | GUI + backend for live data |
| Functional Hull Prototype | 3/5/2026 | Hull integrated with all components |
| Manual | 4/14/2026 | Documentation and user guides |
| Project Final Report | 5/5/2026 | Summary, system specs, results |

---

## 7. DOCUMENTS PRODUCED DURING DISCUSSIONS

The following documents were created through conversations in this project and are available in the project knowledge:

1. **ISR_SWARM_COMMUNICATIONS_SUMMARY.md** — Comprehensive summary of Steps 1-5 implementation, verification results, SRVM mapping, performance metrics, and technology stack details.

2. **SOFTWARE_INTEGRATION_ACTION_ITEM.md** — Full 5-phase integration roadmap with 14 items, dependencies, schedule, risk assessment, testing infrastructure, and success metrics.

3. **ISR_READINESS_CHECKLIST.md** — Pre-ISR preparation guide covering demo preparation, SRVM mapping clarity, range testing, propulsion integration planning, slide structure recommendations, and Q&A preparation.

4. **ISR Presentation Slides** — Power subsystem and communications subsystem slide decks were discussed and refined for the ISR presentation.

---

## 8. IMPORTANT NOTES FOR CLAUDE CODE

- John prefers **technical accuracy over promotional language**. Use verified test results and concrete metrics, not "braggy" stats like lines of code.
- The SRVM (System Requirements Verification Matrix) format is critical for formal engineering reviews.
- When generating documents, John likes **Markdown and Typst** formats (Typst for professional PDF compilation).
- The project uses **GitHub** for code management.
- ESP-IDF v5.5.x is the development framework — all code is C for embedded systems.
- The ESP32-S3 firmware is a **single binary** that runs on all nodes; identity is provisioned at runtime via NVS.
- Formation control (Step 6) was completed and verified on hardware as of Feb 09, 2026, after the ISR_SWARM_COMMUNICATIONS_SUMMARY.md was written (which only covered Steps 1-5). The ISR slides reflect 6/9 steps complete.
- The next coding work is Steps 7-9 (obstacle sensing and avoidance) and the remaining integration phases (propulsion interface, navigation, etc.).
- Wiring was upgraded to 12 AWG post-ISR per judge recommendation — this is the most recent change.

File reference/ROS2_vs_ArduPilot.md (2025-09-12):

# ROS 2 vs. ArduPilot for Navigation and Mission Planning

| Feature | ROS 2 | ArduPilot |
| --- | --- | --- |
| Navigation stack | Nav2 provides path planning and obstacle avoidance for robots, with plugins for marine vessels. | Built-in navigation tailored for UAVs, Rovers, and Boats with mature waypoint navigation. |
| State estimation | Supports `robot_localization` and many filter packages for sensor fusion. | Uses EKF/UKF engines integrating GPS, IMU, and barometer data. |
| Mission planning | Flexible mission scripting via Python/C++ nodes; integration with RViz. | Mission Planner and MAVProxy offer GUI and scripting for complex missions. |
| Hardware support | Requires custom drivers or ROS 2 wrappers for sensors/actuators. | Extensive hardware abstraction through HAL with many supported boards. |
| Community & maturity | Large robotics community, active development. | Long-term autonomy focus, proven in field with extensive documentation. |

**Summary:** ROS 2 excels when integrating diverse software components and advanced autonomy algorithms, especially if a flexible middleware is desired. ArduPilot offers a more turnkey solution with robust navigation and mission capabilities out of the box for small autonomous vehicles. For Aquabot, ArduPilot may reduce development overhead for navigation and mission execution, while ROS 2 is preferable if deep customization or integration with other robotics frameworks is required.

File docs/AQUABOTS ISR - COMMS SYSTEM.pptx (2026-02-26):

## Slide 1

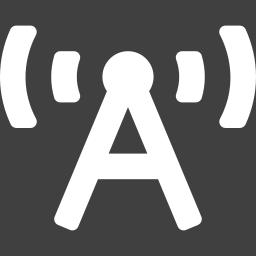
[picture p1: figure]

Communications System

Integration Status Review (ISR)

5/5

Comms Layers

Complete

✓

IF-6 (Drone↔Drone)

Verified

0%

Packet Loss

Complete

<5ms

RTT Latency

Complete

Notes: TALKING POINTS:
- Distributed swarm coordination for 20-50 autonomous surface drones
- ESP32-S3 with ESP-NOW protocol — zero-configuration networking
- All 5 communication layers complete and verified on hardware
- Interface IF-6 (drone-to-drone) fully verified — 0% packet loss, sub-5ms RTT
- Integration Phase 0 (interface specs) starting this week

TIME: 30 seconds

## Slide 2

Hardware Architecture & Status

ESP32-S3 Communication Hardware

ESP32-S3 Specifications

- MCU: Xtensa Dual-Core @ 240 MHz
- Radio: 2.4 GHz WiFi (ESP-NOW)
- Protocol: ESP-NOW (up to 250 kbps)
- Antenna: On-board PCB antenna
- Range: 30m+ indoor, 100m+ outdoor
- Power: 3.3V from distribution board
- UART: 0=Console, 1=Pixhawk, 2=Jetson

THE UNIVERSITY OF ARIZONA

Hardware Status

MCU selected & tested (ESP32-S3)

2-node communication verified

RSSI: -16 to -24 dBm at 1m

Multi-node setup (Phase 1, Wk 8)

Waterproof enclosure (Phase 3, Wk 12-13)

Timeline: Wk 8 → 3rd board + stub tests | Wk 10 → Pair tests | Wk 12 → Full system

AQUABOTS | ISR – Communications System

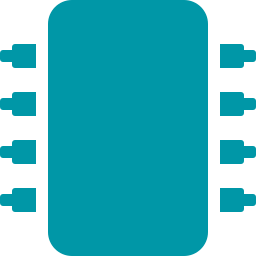
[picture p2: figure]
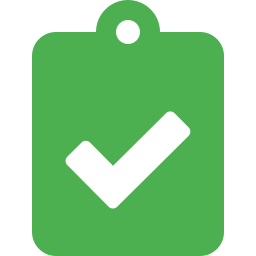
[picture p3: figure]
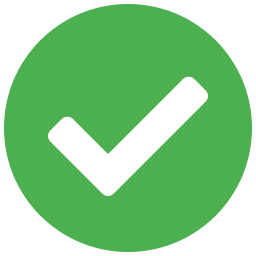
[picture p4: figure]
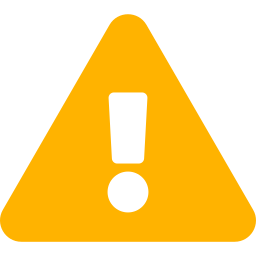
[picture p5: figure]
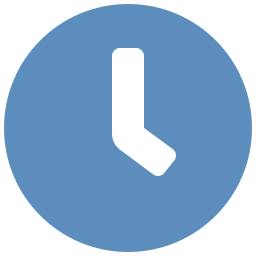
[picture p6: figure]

2

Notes: TALKING POINTS:
- ESP32-S3 selected for dual-core processing, built-in 2.4GHz WiFi
- ESP-NOW eliminates need for WiFi access point — direct peer-to-peer
- Currently verified on 2 development boards
- UART port allocation planned: UART0=console, UART1=Pixhawk (IF-1), UART2=Jetson (IF-3)
- 3rd dev board arriving Week 8 for multi-node and stub testing
- Waterproof enclosure integration during Phase 3 full system testing

TIME: 45 seconds

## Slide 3

Software Stack – Layers 1-5

All 5 communication layers complete and verified on hardware

GOTO, HOLD, STOP, RESUME — synchronized execution

Layer 5: Commands

Key Metrics

~2,350

Lines of Code

5 of 5

Modules

~10 KB

RAM Usage

~800 KB

Flash Usage

<5%

CPU Load

6 weeks

Dev Time

5

✓

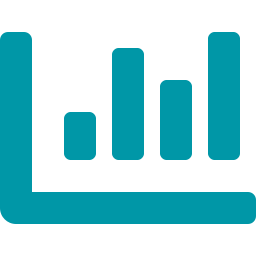
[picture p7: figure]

Leader election (highest ID) + TDMA scheduling (50ms slots)

4

Layer 4: Coordination

✓

HELLO/JOIN auto-discovery — 2-4 sec, 50-node capacity

3

Layer 3: Discovery

✓

NVS provisioning — persistent node IDs (1-254)

2

Layer 2: Identity

✓

ESP-NOW wrapper — 4-5ms RTT, 0% packet loss

1

Layer 1: Transport

✓

THE UNIVERSITY OF ARIZONA

AQUABOTS | ISR – Communications System

3

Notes: TALKING POINTS:
- All 5 communication layers complete — this is the full swarm comm stack
- Layer 1: ESP-NOW wrapper handles all radio communication
- Layer 2: Each drone gets a persistent unique ID via NVS flash
- Layer 3: Drones discover each other automatically — zero-config
- Layer 4: Highest ID drone becomes leader, generates TDMA schedule
- Layer 5: Leader distributes GOTO/HOLD/STOP/RESUME commands
- ~2,350 lines production-quality C code in ESP-IDF
- Very lightweight: <5% CPU, ~10KB RAM
- Note: These 5 layers implement IF-6 (drone↔drone) which is fully complete

TIME: 60 seconds

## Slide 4

SRVM Verification – Requirement 4.4.2

Inter-Drone Communication: PARTIAL PASS → Advancing to FULL PASS

Verification Method | Status | Evidence / Detail | Date
TEST | ✓ PASS | RTT <5ms | 0% loss | RSSI -16 to -24 dBm | Discovery <5s | Wk 6
DEMONSTRATION | ✓ PASS | 2-node swarm: auto-discovery, leader election, TDMA, cmd sync | Wk 6
ANALYSIS | ◐ In Progress | Scalability 2→50 nodes, traffic modeling, performance projections | Wk 9
INSPECTION | ○ Planned | Hardware inspection, antenna placement, enclosure RF check | Wk 12

- 4.1.2 Swarm Control — Demonstration: ✓ PASS (leader election, synchronized commands)
- 4.4.1 Autonomy & Control — Demonstration: ◐ PARTIAL (command execution OK, formation pending)
- 4.3.1 Survivability — Test: ✓ PASS (0% packet loss) | Analysis: Scheduled Wk 9

AQUABOTS | ISR – Communications System

Supporting Requirements

THE UNIVERSITY OF ARIZONA

4

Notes: TALKING POINTS:
- Requirement 4.4.2 currently at PARTIAL PASS, advancing to FULL PASS
- TEST: All metrics exceed requirements — RTT <5ms, 0% packet loss, excellent signal
- DEMONSTRATION: Full 2-node swarm demonstrated — discovery through command execution
- ANALYSIS: Scalability study scheduled during Spring Break buffer (Wk 9)
- INSPECTION: Hardware inspection during Phase 3 full system integration (Wk 12)
- Supporting requirements also on track

TIME: 60 seconds

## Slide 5

Live Demonstration

2-Node Swarm Communication — End-to-End Verification

Power On

Two ESP32-S3 boards powered up

Auto-Discovery

Nodes discover each other (2-4 sec)

Leader Election

Node 2 (highest ID) elected leader

1

2

3

TDMA Schedule

Leader generates 50ms time slots

4

Send Command

Leader sends: goto 100 200 90

5

Synchronized Exec

Both nodes receive & execute

6

Backup: Pre-recorded video + console screenshots available if live demo encounters issues

AQUABOTS | ISR – Communications System

THE UNIVERSITY OF ARIZONA

5

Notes: TALKING POINTS:
- Live demo: Watch two ESP32-S3 boards coordinate in real-time
- Power on → automatic discovery in 2-4 seconds
- Node 2 becomes leader (highest ID wins)
- Leader generates TDMA schedule — 50ms slots prevent collisions
- Leader sends GOTO command — both nodes receive and execute
- Console shows synchronized status on both boards
- Backup video ready if hardware has issues

TIME: 2 minutes for demo

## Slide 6

Software Integration Plan

5 Phases (0-4) — Integration-Maturity Model with Team Pairings

Phase 0: Interface Agreement

5 interface specs (IF-1 to IF-5); team sign-off by Feb 28

John's IF Ownership

- IF-1: Swarm ↔ Pixhawk (w/ Robert)
- IF-2: Sensors → ESP32 (w/ Jamie)
- IF-3: ESP32 ↔ Jetson (w/ Jamie)
- IF-5: GUI Cmds → Drone (w/ Mayra)
- IF-6: Drone ↔ Drone ✓ DONE

Wk 7

IN PROGRESS

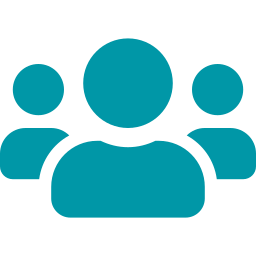
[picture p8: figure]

Phase 1: Pairwise Stub Testing

Each IF tested: one real side + one stub; Spring Break buffer Wk 9

Wk 8-9

Upcoming

Phase 2: Subsystem Pair Integration

Real HW connected in pairs — Swarm↔Pixhawk, Sensors↔ESP32, GUI↔Jetson

Wk 10-11

Planned

Phase 3: Full System Integration

All 4 subsystems running on complete drone; 2-drone swarm; E-STOP

Wk 12-13

Planned

Critical Path

IF-1: Swarm ↔ Pixhawk

- Two MCUs, two owners, real-time protocol
- Tested earliest; most schedule buffer
- MAVLink over UART — spec due Feb 26

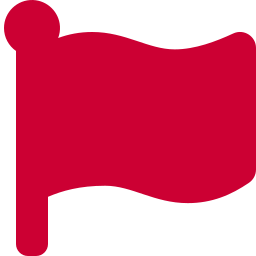
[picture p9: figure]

Phase 4: Pool Testing & Validation

Single-drone pool → multi-drone pool → full mission test

THE UNIVERSITY OF ARIZONA

Wk 14-15

Planned

AQUABOTS | ISR – Communications System

6

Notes: TALKING POINTS:
- Integration plan follows 5 phases (0-4) based on integration maturity, NOT subsystem breakdown
- Phase 0 (THIS WEEK): All 4 team members agree on interface specs — IF-1 through IF-5
- IF-6 (drone↔drone ESP-NOW) already complete and verified
- Phase 1 (Wk 8-9): Stub testing — each interface tested with one real side + one mock
- Spring Break (Wk 9) used as buffer
- Phase 2 (Wk 10-11): Real hardware pairs connected — Swarm↔Pixhawk is first (critical path)
- Phase 3 (Wk 12-13): Full system on complete drone, 2-drone swarm, E-STOP
- Phase 4 (Wk 14-15): Pool testing — single then multi-drone
- CRITICAL PATH: IF-1 (Swarm↔Pixhawk) — two MCUs, two team members, real-time MAVLink
- Must be tested earliest with most schedule buffer
- I own or co-own 5 of 6 interfaces (IF-1, 2, 3, 5, 6)

TIME: 60 seconds

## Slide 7

Testing & Validation Results

Verified Performance Metrics — Requirement 4.4.2

RTT Latency

4-5 ms

Req: <10 ms

Packet Loss

0%

Req: <5%

Signal Strength

-16 to -24 dBm

Req: >-70 dBm

Discovery Time

2-4 sec

Req: <5 sec

PASS

PASS

PASS

PASS

Test Case | Result | Detail
Auto-Discovery (2 nodes) | ✓ PASS | Both nodes discovered in 2-4 seconds
Leader Election | ✓ PASS | Highest node_id (Node 2) elected correctly
TDMA Scheduling | ✓ PASS | 50ms slots generated, beacon every 1s
Command Distribution | ✓ PASS | GOTO/HOLD/STOP/RESUME — <50ms latency
Leader Failover | ✓ PASS | Auto re-election in 5-7 sec after power-off
Thread Safety | ✓ PASS | Mutex protection, zero race conditions

AQUABOTS | ISR – Communications System

Functional Verification Results

THE UNIVERSITY OF ARIZONA

7

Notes: TALKING POINTS:
- All performance metrics EXCEED requirements
- RTT 4-5ms against <10ms plan requirement — well within threshold
- Packet loss is 0% — well below 5% requirement
- Signal strength -16 to -24 dBm — far exceeds -70 dBm minimum
- Discovery in 2-4 seconds — well under 5 second requirement
- All functional tests pass: discovery, election, scheduling, commands, failover
- Thread safety verified — no race conditions with mutex protection
- These metrics verified per Integration Plan Section 6.1

TIME: 45 seconds

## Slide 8

Master Integration Timeline

Integration Schedule and Key Milestones

Wk

Ph 0: IF Specs

NOW

7

8

BREAK

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
Ph 1: Stub Testing

Ph 2a: Swarm↔Pixhawk

Ph 2a: Sensors↔ESP32

Ph 2b: E2E Command

Ph 3a: Full Stack

Ph 3b: 2-Drone Swarm

Ph 4: Pool Testing

Finalize + Submit

In Progress

THE UNIVERSITY OF ARIZONA

John's Tasks

Critical Path (IF-1)

Pair/System Tests

AQUABOTS | ISR – Communications System

8

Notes: TALKING POINTS:
- Timeline matches Software Integration Plan Master Timeline (Section 10)
- Week 7 (NOW): Phase 0 — finalizing interface spec documents with all teammates
- IF1_SPEC.md (John+Robert), IF2_SPEC.md (Jamie+John), IF3_SPEC.md (John+Jamie)
- IF5_SPEC.md (Mayra+John) — team sign-off meeting Feb 28
- Week 8: Phase 1 — pairwise stub testing — each interface one real side + one stub
- Week 9: Spring Break — buffer for async catch-up
- Week 10: Phase 2a — CRITICAL: Swarm↔Pixhawk pair test (John+Robert)
- ESP32 goto → Pixhawk motor spins, rudder deflects, ACK received
- Week 11: Phase 2b — End-to-end command chain: GUI→MQTT→Jetson→ESP32→Pixhawk
- Weeks 12-13: Phase 3 — Full system on drone, then 2-drone swarm + E-STOP
- Weeks 14-15: Phase 4 — Pool testing (single then multi-drone)
- Weeks 16-17: Finalize documentation and submit

TIME: 45 seconds

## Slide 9

Next 30 / 60 / 90 Day Plan

Milestones, Deliverables, and Integration Targets Through May

30 Days

Feb 24 – Mar 27

- Wk 7: IF-1, IF-2, IF-3, IF-5 specs agreed
- Wk 7: Team sign-off meeting (Feb 28)
- Wk 8: ESP32 sends MAVLink GOTO/STOP (1.1)
- Wk 8: ESP32 reads sensor structs (1.4)
- Wk 8: ESP32↔Jetson serial packets (1.8)
- Wk 9: Spring Break buffer / catch-up
- Wk 10: Swarm↔Pixhawk pair test (2.1)
- Wk 10: Live sensor flow into ESP32 (2.2)
- Wk 11: E2E cmd: GUI→ESP32→Pixhawk (2.4)
- Wk 11: 2-drone swarm + Pixhawk (2.5)

THE UNIVERSITY OF ARIZONA

60 Days

Mar 27 – Apr 24

- Wk 12: Single-drone full stack (3.1)
- Wk 13: 2-drone swarm full system (3.2)
- Wk 13: Sensor readings during motion (3.3)
- Wk 13: E-STOP verified < 2 sec (3.4)
- Wk 13: Starlink loss → auto HOLD (3.5)
- Wk 14: Single-drone pool test (4.1)
- Wk 15: Multi-drone pool test (4.2)
- Wk 15: Full mission validation (4.3)

AQUABOTS | ISR – Communications System

90 Days

Apr 24 – May 7

- Wk 16: Manual & documentation
- Wk 16: Design Day preparation
- Wk 17: Final report submission
- Performance optimization
- Integration test reports finalized

10

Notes: TALKING POINTS:
- 30 Days: Focus on Phase 0-2 — interface specs, stub testing, pair integration
- THIS WEEK: All interface specs agreed — IF-1 through IF-5
- Week 8: Stub testing — ESP32 sends MAVLink, reads sensors, talks to Jetson
- Week 10: CRITICAL — Swarm↔Pixhawk pair test with Robert
- Week 11: End-to-end command chain verified
- 60 Days: Phase 3-4 — Full system and pool testing
- Single-drone full stack, then 2-drone swarm
- E-STOP verified, Starlink loss graceful degradation
- Pool testing: single then multi-drone missions
- 90 Days: Finalize — documentation, Design Day, final report
- Task numbers (e.g., 1.1, 2.1) reference Integration Plan directly

TIME: 45 seconds

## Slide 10

Risk Assessment & Mitigation

From Software Integration Plan — Risk Register (Section 8)

Risk | Prob | Impact | Mitigation | Owner
R1: MAVLink format mismatch ESP32↔Pixhawk | Med | High | Spec in Phase 0; logic analyzer in Phase 1 | John+Robert
R2: Starlink latency too high for control | Low | Med | Critical control via ESP-NOW; Starlink for telemetry | Mayra+John
R3: Sensor noise during motor vibration | Med | Med | Test during operation Phase 3; add filtering | Jamie
R5: UART port contention on ESP32 | Med | Med | UART0=console, 1=Pixhawk, 2=Jetson; verify early | John
R6: Spring Break schedule slip | High | Med | Front-load Phase 1 critical tasks to Week 8 | ALL
R7: Waterproofing failure | Med | High | Bench-test all integration before pool; conformal coat | ALL
R8: Pixhawk firmware incompatibility | Low | High | Verify firmware + MAVLink v2 in Phase 0 | Robert

Completed Mitigations

- IF-6 protocol reliability: 0% packet loss verified
- Auto-discovery, leader election, thread safety: all verified

THE UNIVERSITY OF ARIZONA

Highest Priority

- R1: MAVLink mismatch — spec due Feb 26
- R6: Spring Break — front-loading Week 8 work

AQUABOTS | ISR – Communications System

9

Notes: TALKING POINTS:
- Risks pulled directly from Software Integration Plan Section 8
- R1 (MAVLink mismatch) is highest priority — on critical path
- Mitigation: formal spec document due Feb 26, logic analyzer verification in Phase 1
- R5 (UART contention) is my responsibility — already planned allocation
- R6 (Spring Break slip) mitigated by front-loading Phase 1 tasks to Week 8
- IF-6 risks already mitigated — proven 0% packet loss, working auto-discovery
- R7 (waterproofing) — all integration bench-tested before going to pool

TIME: 45 seconds

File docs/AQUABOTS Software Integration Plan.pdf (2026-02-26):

# AQUABOTS

# Software Integration Plan

## ENGR 498B — Spring 2026

### ISR Action Item Deliverable

### Document Owner: John — Software Integration Lead Date: February 20, 2026 Status: Pre-ISR Deliverable Version: 1.0

AQUABOTS Software Integration Plan | ENGR 498B — Spring 2026

# Contents

# 1 Purpose

### This document defines the concrete, step-by-step plan for integrating all software subsystems into a single AQUABOTS system. It specifies who does what, when, what

interfaces connect the subsystems, and how we verify that each integration point works.

# 2 Team Roles & Subsystem Ownership

Member | Subsystem | Hardware | Software Stack
John | Swarm Communications | ESP32 (2+ boards) | ESP-IDF/C — ESPNOW transport, discovery, leader election, TDMA, command engine
Jamie | Sensors & Data Acquisition | pH, temp, salinity probes | Jetson Orin Nano — sensor drivers, data logging, 1080p/30fps camera stream
Mayra | GUI & Ground Station | Operator laptop, Starlink terminal; IMX219 camera | GUI dashboard, GeoOverlay, live-video, Cloud MQTT, Starlink uplink
Robert | Propulsion & Flight Control | Pixhawk, ESC, motor, rudder servo | Pixhawk firmware / MAVLink — motor control, rudder steering, waypoint execution

# 3 System Architecture & Integration Interfaces

### The CDR block diagram defines six buses that cross subsystem boundaries. Each bus is

an integration interface that must be formally defined, implemented, and verified.

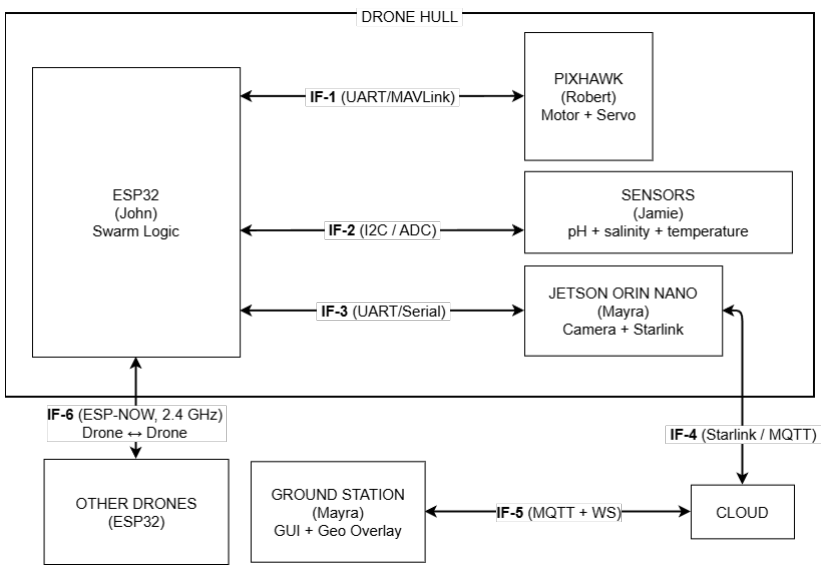
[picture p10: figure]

Figure 1: System integration architecture showing all six interface boundaries.

## 3.1 Interface Definitions

ID | Interface | From → To | Protocol | Data | Owners
IF-1 | Swarm ↔ Propulsion | ESP32 ↔ Pixhawk | MAVLink / UART | GOTO, HOLD, STOP commands; position telemetry | John + Robert
IF-2 | Sensors → Compute | Probes → ESP32/Jetson | I2C, 1-Wire, CSI | pH, temp, salinity, video | Jamie + John
IF-3 | ESP32 ↔ Jetson | ESP32 → Jetson | UART 115200 | Swarm state, sensor relay, commands | John + Jamie
IF-4 | Drone ↔ Cloud | Jetson → MQTT | MQTT/TLS | Telemetry, sensor data, video | Jamie + Mayra
IF-5 | Ground Station Cloud ↔ | MQTT → GUI | MQTT + WS | Telemetry display, operator commands | Mayra
IF-6 | Drone ↔ Drone | ESP32 ↔ ESP32 | ESP-NOW | Discovery, election, commands | John (done)

# 4 Current Status (as of Feb 20, 2026)

Subsystem | Status | Evidence
Swarm Comms (John) | Steps 1–5 ✅ | 2-node verified; RTT < 5ms, 0% loss, leader election, command distribution
Sensors (Jamie) | Mounted ✅ | Sensor suite mounted per CDR (12/2/25)
GUI & GS (Mayra) | CDE-1 verified ✅ | Two-way Starlink data link; GUI prototype with live video + remote command; IMX219 at 1080p/30fps at CDE-1
Propulsion (Robert) | In progress 🟡 | Propulsion deliverable due 2/19/26; Pixhawk + ESC under test

# 5 Integration Schedule

Phase 0: Interface Agreement | Week 7 — Feb 24–28

### Goal: All four team members formally agree on every interface definition. No code —

just the contracts.

Task | Owner(s) | Deliverable | Due | Verification
0.1 | John + Robert | IF1_SPEC.md — MAVLink message IDs, fields, units, rates | Feb 26 | Both independently describe same format
0.2 | Jamie + John | IF2_SPEC.md — sensor data struct/ schema per sensor | Feb 26 | Driver output matches expected input
0.3 | John + Jamie | IF3_SPEC.md — ESP32↔Jetson packet framing, baud | Feb 27 | Loopback test: 100% packet integrity
0.4 | Jamie + Mayra | IF4_SPEC.md — MQTT topics + JSON payloads | Feb 27 | Test publish → GUI receives
0.5 | Mayra + John | IF5_SPEC.md — GUI command topics + ACK flow | Feb 28 | GUI sends waypoint, drone logs receipt

0.6 | ALL | Team sign-off (30-min meeting) | Feb 28 | Each person confirms their interfaces

### Exit Criteria: - All 5 interface spec documents committed to shared repo (IF-6 already complete) - Each spec has: message format, units, sample rates, error codes - Every team member has signed off

Phase 1: Pairwise Stub Integration | (Weeks 8–9 — Mar 2–13)

### Goal: Each interface tested with one real side + one stub. Spring Break is Week 9 —

front-load critical work to Week 8.

Task | Owner | What | Due | Pass Criteria
1.1 | John | ESP32 sends GOTO/STOP MAVLink over UART; verify with serial monitor | Mar 3 | Correct MAVLink framing on TX
1.2 | Robert | Pixhawk parses MAVLink GOTO; returns ACK | Mar 5 | ACK received by ESP32 < 100ms
1.3 | Jamie | Each sensor driver outputs IF-2 struct; unit tests | Mar 3 | pH ±0.1, temp ±0.5°C, salinity ±1 ppt
1.4 | John | ESP32 reads IF-2 structs; logs to console | Mar 5 | Valid readings at 1 Hz on console
1.5 | Jamie | Jetson publishes stub telemetry to MQTT | Mar 3 | MQTT Explorer shows correct topic
1.6 | Mayra | GUI subscribes; displays data + GeoOverlay | Mar 5 | Dashboard updates < 2s after publish
1.7 | Mayra | GUI GOTO button → MQTT command | Mar 6 | Jetson logs receipt
1.8 | John + Jamie | ESP32↔Jetson bidirectional serial packets | Mar 6 | 100% integrity over 1000 packets
Phase 2: Subsystem Pair Integration | (Weeks 10–11 — Mar 16–27)

Goal: Real subsystems connected in pairs — real data, real hardware.

Task | Pair | What | Due | Pass Criteria
2.1 | John + Robert | ESP32 goto 100 200 → Pixhawk executes motor move | Mar 19 | Motor spins; rudder deflects; ACK received
2.2 | Jamie + John | Live pH/temp/salinity flow into ESP32 at 1 Hz | Mar 19 | Console shows real values within tolerance
2.3 | Jamie + Mayra | Jetson publishes live sensor + camera via Starlink to GUI | Mar 23 | Dashboard shows live data; video < 5s latency
2.4 | Mayra + John | GUI click → MQTT → Jetson → ESP32 → Pixhawk | Mar 26 | End-to-end < 10s; Pixhawk logs waypoint
2.5 | John + Robert | Leader GOTO → both drones execute → Pixhawk on each | Mar 27 | Both motors activate within 100ms

Phase 3: Full System Integration | (Weeks 12–13 — Mar 30 – Apr 10)

Goal: All four subsystems running simultaneously on a complete drone.

Task | Owner | What | Due | Pass Criteria
3.1 | ALL | Single-drone full stack: GUI→Starlink→Jetson→ESP32→Pixhawk; sensors stream back | Apr 2 | Full loop; GUI shows position + sensor data
3.2 | ALL | Two-drone swarm: leader election, synchronized GOTO, both report to GUI | Apr 7 | Both move; GeoOverlay shows 2 icons
3.3 | Jamie + John | Sensor readings valid while drone moving (vibration test) | Apr 7 | Readings within spec during 60s of nav
3.4 | ALL | E-STOP: GUI button → both drones halt within 2 seconds | Apr 9 | Motors off < 2s; GUI shows STOPPED
3.5 | ALL | Graceful degradation: kill Starlink → drones hold autonomously | Apr 10 | Drones HOLD; resume on link restore
Phase 4: Pool Testing & Validation | (Weeks 14–15 — Apr 13–24)
Task | Owner | What | Due | Pass Criteria
4.1 | ALL | Single-drone pool: GOTO, HOLD, sensor collection, GUI display | Apr 16 | Waypoint ±1m; hold ±0.5m; data at GUI
4.2 | ALL | Multi-drone pool: synchronized movement, no collisions | Apr 21 | Formation ±1m; no collisions
4.3 | ALL | Full mission: deploy, navigate pattern, collect data, return | Apr 24 | Mission completes; all data captured

# 6 Integration Verification Metrics

## 6.1 Communication & Latency

Metric | Requirement | Measurement Method | Owner
ESPNOW RTT (drone↔drone) | < 10 ms | Timestamp in TX, measure at RX | John
(ESP32→Pixhawk) MAVLink latency | < 100 ms | Send timestamp vs ACK timestamp | John + Robert
(drone→cloud→GUI) MQTT round-trip | < 5 s | Payload timestamp vs GUI display time | Jamie + Mayra
E-STOP response (GUI→motor off) | < 2 s | Button timestamp → motor current = 0 | ALL
Swarm command sync | < 100 ms between nodes | Compare execution timestamps | John

## 6.2 Sensor Data Integrity

Metric | Requirement | Measurement Method | Owner
pH accuracy | ± 0.1 pH | Calibrated reference probe | Jamie
Temperature accuracy | ± 0.5 °C | NIST-traceable thermometer | Jamie
Salinity accuracy | ± 1 ppt | Known solution | Jamie
Sensor sample rate | ≥ 1 Hz sustained | Count readings over 60 s | Jamie + John
Data loss (sensor→GUI) | < 1% | Sensor log count vs GUI count | Jamie + Mayra
Camera latency | < 5 s | Clock in frame vs display time | Jamie + Mayra
Camera resolution | 1080p @ 30fps | Stream properties inspection | Jamie

## 6.3 Propulsion & Navigation

Metric | Requirement | Measurement Method | Owner
Waypoint accuracy | ± 1 m | GPS vs commanded waypoint | Robert + John
Heading accuracy | ± 5° | IMU heading vs command | Robert
Position hold drift | ± 0.5 m / 60 s | GPS log during HOLD | Robert + John
E-stop motor response | < 500 ms | Current sensor timestamp | Robert

## 6.4 Ground Station & GUI

Metric | Requirement | Measurement Method | Owner
Dashboard update rate | ≥ 1 Hz | Count refreshes over 60 s | Mayra
GeoOverlay accuracy | Matches GPS ± 2 m | GUI marker vs drone position | Mayra + John
Command ACK latency | < 5 s | Button press to ACK display | Mayra
Multi-drone display | All drones visible | Visual inspection with 2 + drones | Mayra
Video uptime | > 95% | Dropped frames / total | Mayra + Jamie

## 6.5 System-Level

Metric | Requirement | Measurement Method | Owner
Battery life | > 30 min | Timed full-charge to cutoff | ALL
ESP32 CPU utilization | < 50% | vTaskGetRunTimeStats() | John
ESP32 heap usage | < 200 KB | esp_get_free_heap_size() | John
Starlink loss recovery | Drones hold position | Kill Starlink, observe | ALL
Reboot recovery | Rejoin swarm < 30 s | Power cycle, measure | John + Robert

# 7 Integration Test Procedures

## 7.1 Test T-01: Swarm ↔ Propulsion (IF-1)

Setup: ESP32 → Pixhawk via UART. Motor on test stand.

Step | Action | Expected Result | P/F
1 | Power on ESP32 + Pixhawk | Both boot; serial link established
2 | Console: goto 100 200 90 | MAVLink GOTO sent; ACK < 100ms
3 | Observe motor | Motor spins; rudder deflects toward 90°
4 | Console: hold | Motor adjusts to maintain position
5 | Console: stop | Motor off within 500ms
6 | Check telemetry | Position/heading updates ≥1 Hz on console

## 7.2 Test T-02: Sensors → Data Pipeline (IF-2 + IF-3 + IF-4)

Setup: Sensors → ESP32/Jetson → Starlink → GUI.

Step | Action | Expected Result | P/F
1 | pH probe in pH 7.0 buffer | ESP32 reads 7.0 ± 0.1
2 | Check Jetson | Receives pH reading via serial
3 | Check MQTT broker | aquabot/1/sensor/ph shows 7.0
4 | Check GUI | Dashboard gauge shows 7.0 ± 0.1
5 | Repeat for temp (ice water) | End-to-end shows 0°C
6 | Run 60 seconds | ≥60 readings at GUI; loss < 1%

## 7.3 Test T-03: Ground Station Command Loop (IF-5 → IF-1)

Setup: GUI on laptop. Starlink active. ESP32 + Pixhawk on drone.

Step | Action | Expected Result | P/F
1 | Click waypoint on GeoOverlay | GUI publishes MQTT command
2 | Check Jetson | Receives command, forwards to ESP32
3 | Check ESP32 | Console: “Command received: GOTO …”
4 | Check Pixhawk | Receives MAVLink GOTO, sends ACK
5 | Check GUI | ACK displayed within 5 seconds
6 | Click E-STOP | Motors off < 2s; GUI shows STOPPED

## 7.4 Test T-04: Full System Smoke Test

Setup: Complete drone on test stand. All subsystems powered. GUI via Starlink.

Step | Action | Expected Result | P/F
1 | Power on drone | All boot < 30s; ESP32 joins swarm; Jetson connects Starlink
2 | Check GUI | Drone icon on GeoOverlay at correct position
3 | Check sensors | pH, temp, salinity visible on dashboard
4 | GUI: send GOTO | Motor activates; status = NAVIGATING
5 | Wait for arrival | GUI shows ARRIVED
6 | GUI: send HOLD | Motors adjust to maintain position
7 | GUI: send STOP | Motors off; status = STOPPED
8 | Kill Starlink | Drone enters autonomous HOLD
9 | Restore Starlink | Drone reconnects; GUI shows live data

# 8 Risk Register

# | Risk | Prob | Impact | Mitigation | Owner

R1 | MAVLink format mismatch ESP32↔Pixhawk | Med | High | Spec in Phase 0; logic analyzer in Phase 1 | John + Robert
R2 | Starlink latency too high for control | Low | Med | Critical control via ESP-NOW; Starlink for telemetry only | Mayra + John
R3 | Sensor noise during motor vibration | Med | Med | Test during operation in Phase 3; add filtering | Jamie
R4 | MQTT broker downtime | Low | High | Retained messages + Jetson local fallback; drones HOLD | Mayra + Jamie
R5 | UART port contention on ESP32 | Med | Med | UART0=console, UART1=Pixhawk, UART2=Jetson; verify early | John
R6 | Spring Break schedule slip | High | Med | Front-load Phase 1 critical tasks to Week 8 | ALL
R7 | Waterproofing failure | Med | High | Bench-test all integration before pool; conformal coating | ALL
R8 | Pixhawk firmware incompatibility | Low | High | Verify firmware + MAVLink v2 support in Phase 0 | Robert

# 9 Dependencies & Critical Path

### The critical path runs through IF-1 (Swarm ↔ Pixhawk) because it involves two

microcontrollers from different team members communicating over a real-time protocol. This interface must be tested earliest and given the most schedule buffer.

Phase 0 (Specs)
├──► Phase 1.1-1.2 (Swarm↔Propulsion stubs) ──► Phase 2.1 (Pair)
├──► Phase 1.3-1.4 (Sensors↔ESP32 stubs) | ──► Phase 2.2 (Pair)
├──► Phase 1.5-1.7 (Jetson↔GUI stubs) | ──► Phase 2.3 (Pair)
└──► Phase 1.8 (ESP32↔Jetson serial) | ──► Phase 2.4 (E2E)
│
| ▼
Phase 3 (Full system) ──► Phase 4 (Pool)

# 10 Master Timeline

Week | Dates | Phase | Key Milestone
7 | Feb 24–28 | Phase 0 | ISR; all interface specs agreed and signed
8 | Mar 2–6 | Phase 1 | Pairwise stub testing complete
9 | Mar 9–13 | Break | Buffer / async catch-up
10 | Mar 16–20 | Phase 2a | Swarm↔Propulsion + Sensors↔ESP32 pair-tested
11 | Mar 23–27 | Phase 2b | Jetson↔GUI + end-to-end command pair-tested
12 | Mar 30 – Apr 3 | Phase 3a | Single-drone full-stack passes
13 | Apr 6–10 | Phase 3b | Two-drone swarm passes; E-STOP verified
14 | Apr 13–17 | Phase 4a | Single-drone pool test
15 | Apr 20–24 | Phase 4b | Multi-drone pool + full mission test
16 | Apr 27 – May 1 | Finalize | Manual, documentation, Design Day prep
17 | May 5 | Submit | Final report due

# 11 Deliverables Checklist

Documents (due end of Phase 0 — Feb 28): - IF1_SPEC.md — MAVLink definitions (John + Robert) - IF2_SPEC.md — Sensor data structs (Jamie + John) - IF3_SPEC.md — ESP32↔Jetson serial protocol (John + Jamie) - IF4_SPEC.md — MQTT topic tree + payloads (Jamie + Mayra) - IF5_SPEC.md — GUI command protocol (Mayra + John)

### Note: IF-6 (Drone ↔ Drone, ESP-NOW) is already complete and verified — no

additional spec required.

### Test Reports (due at each phase gate): - Phase 1 results (Mar 6) - Phase 2 results (Mar 27) - Phase 3 results (Apr 10) - Phase 4 results (Apr 24)

# 12 Communication & Coordination

What | How | Frequency
Integration standup | In-person or Discord | 2×/week (Tue/Thu)
Spec reviews | Pull request on GitHub | As drafted (Phase 0)
Test results | Shared Drive folder | After each test session
Blocker escalation | Group chat + standup | As needed
Phase gate review | 15-min team meeting | End of each phase

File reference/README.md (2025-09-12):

# Aquabot_25030
Repository for all files used in the final product produced by Aquabot team 25030, academic year 24/25

## Backend and Frontend

This repository now includes a simple MQTT-enabled backend service and a web dashboard.

- **backend/** contains a FastAPI application that connects to an MQTT broker and exposes REST and WebSocket APIs.
- **frontend/** provides a small React-based interface for map display, sensor charting, and command controls.

The backend uses an in-memory user database with `operator` and `viewer` roles. Tokens are returned from `/token` and should be included as `Bearer` tokens when calling protected endpoints.

The frontend can be opened directly by loading `frontend/index.html` in a browser.

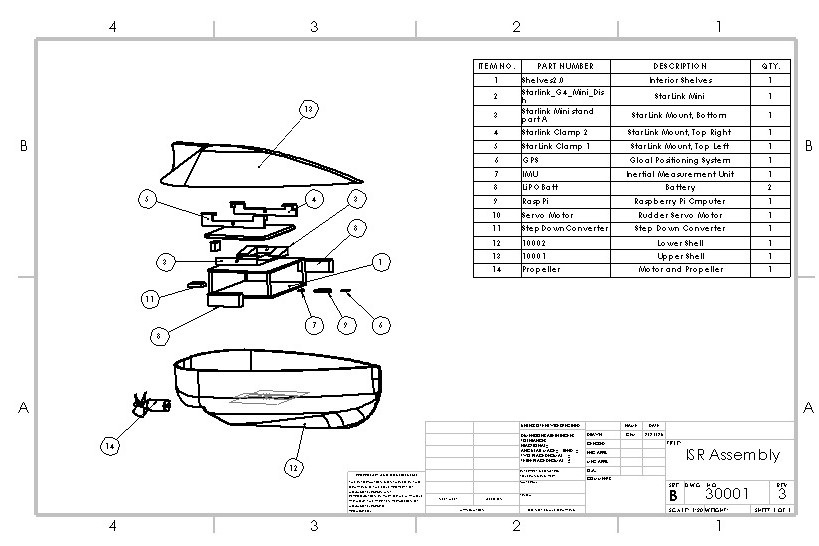
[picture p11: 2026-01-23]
reference/BoatWithElectronicsDrawingJPEG.JPG

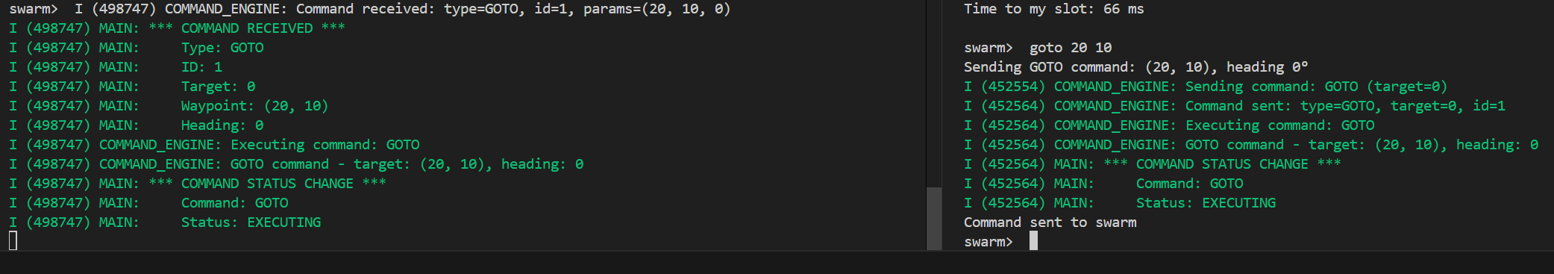
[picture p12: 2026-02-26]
docs/pics/goto.png

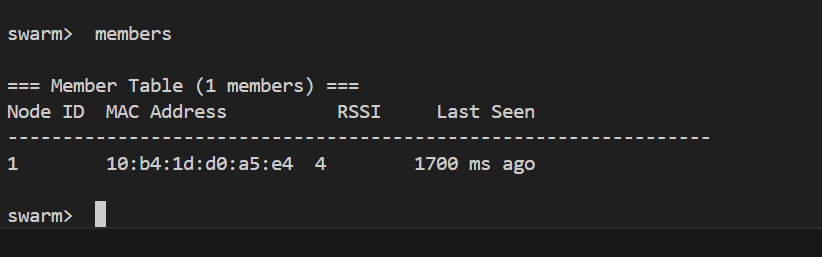
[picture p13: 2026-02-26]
docs/pics/members.png

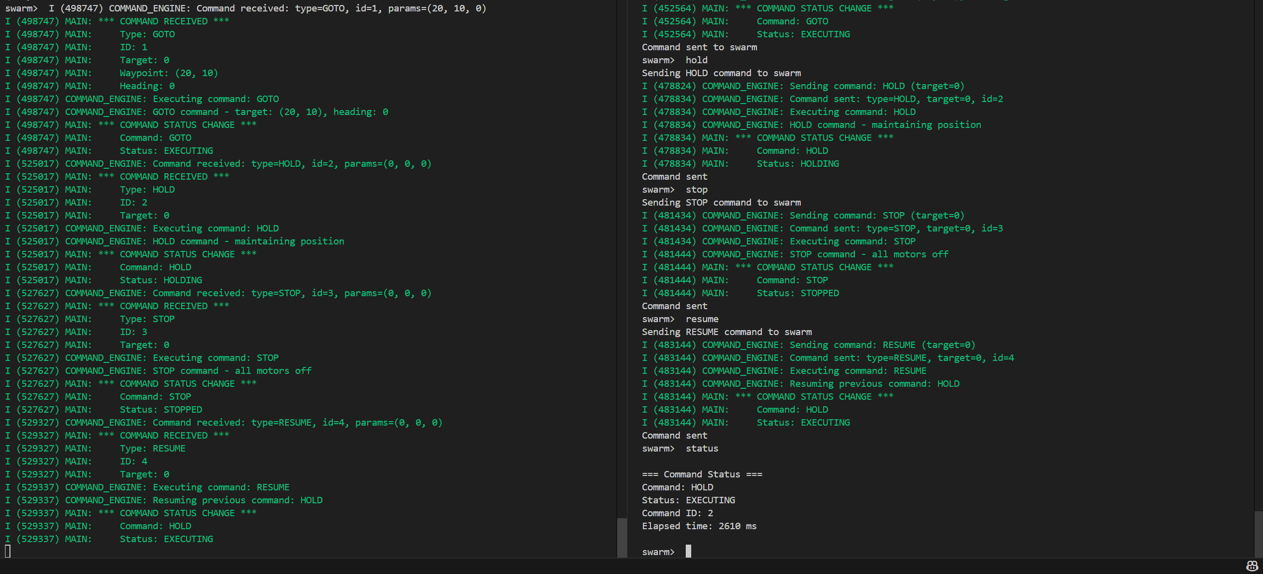
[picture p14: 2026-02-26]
docs/pics/other commands.png

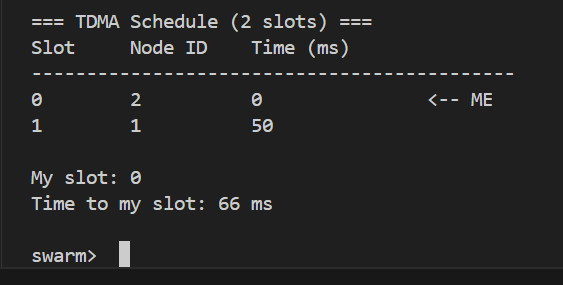
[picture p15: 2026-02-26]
docs/pics/schedule.png

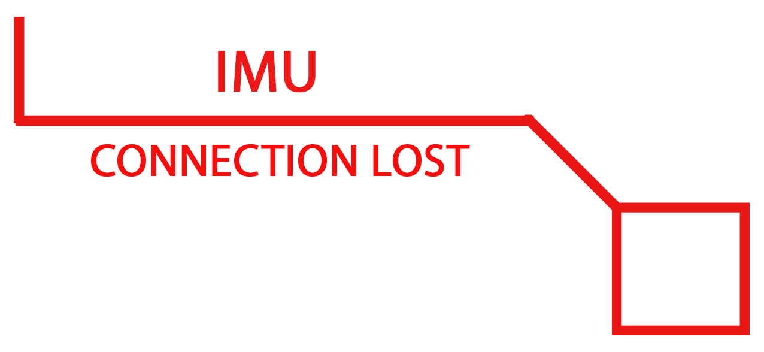
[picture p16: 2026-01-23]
reference/ground_station_folder/graphics/IMUB.png

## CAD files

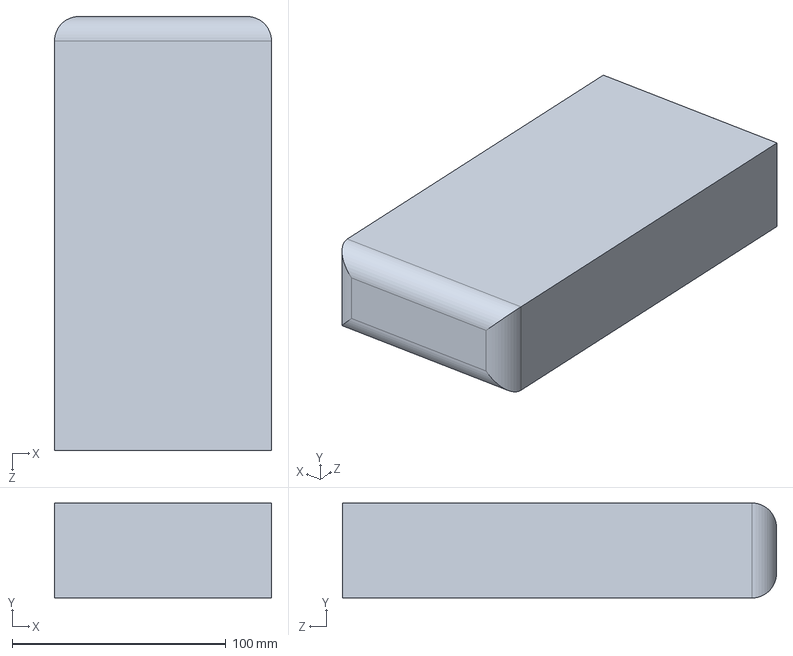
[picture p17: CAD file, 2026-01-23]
reference/Battery3.SLDPRT
101.6 x 44.5 x 203.2 mm

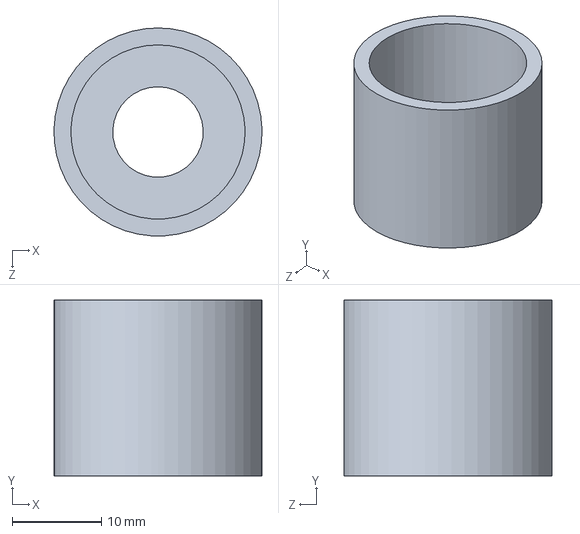
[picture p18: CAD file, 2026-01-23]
reference/Shelf Parts/ShelfSupportEndCaps.SLDPRT
23.4 x 19.8 x 23.4 mm

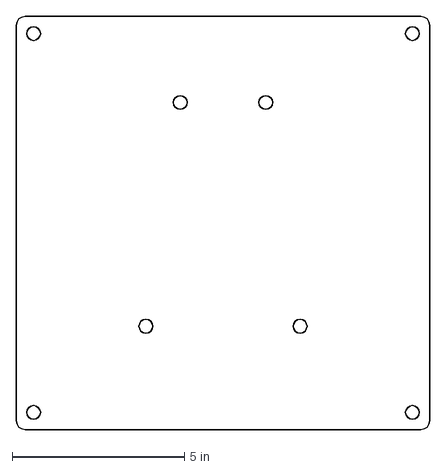
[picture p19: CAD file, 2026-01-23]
reference/cmauldin_topShelf.DXF
12.0 x 12.0 in

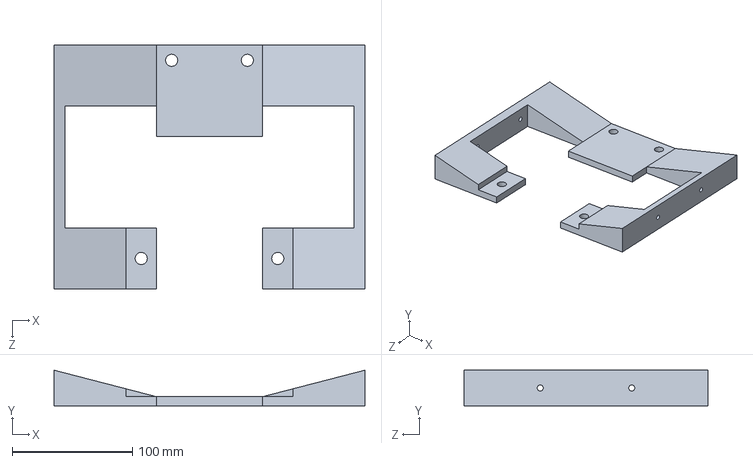
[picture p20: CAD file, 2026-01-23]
reference/Shelf Parts/Starlink Mini stand part A.SLDPRT
259.1 x 29.7 x 203.2 mm

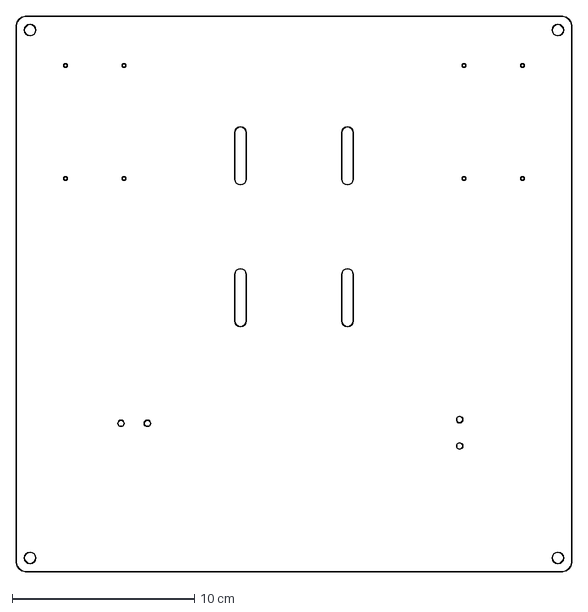
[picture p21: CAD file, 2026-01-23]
reference/cmauldin_BottomShelf3.1_corrected.DXF
30.5 x 30.5 cm

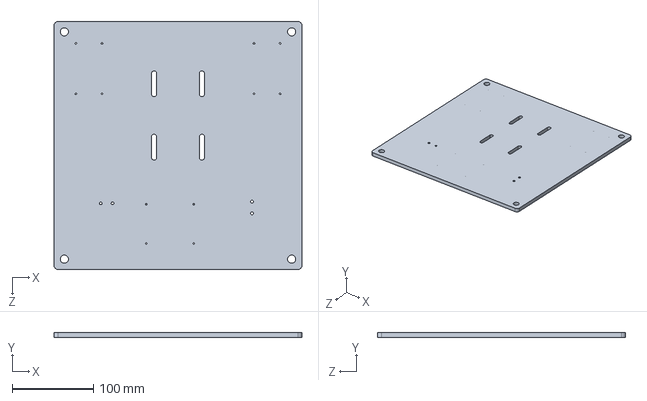
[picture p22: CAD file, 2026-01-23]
reference/Shelf Parts/BottomShelf3.1.SLDPRT
304.8 x 6.35 x 304.8 mm

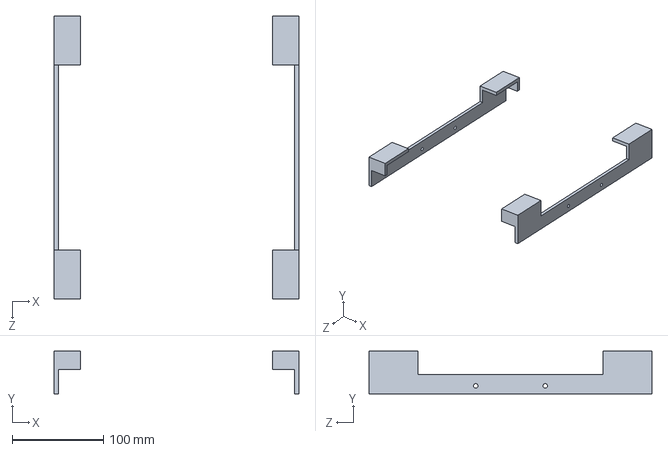
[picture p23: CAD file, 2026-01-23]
reference/Assemblies/Starlink Mini stand part B.SLDPRT
268.6 x 46.7 x 309.9 mm

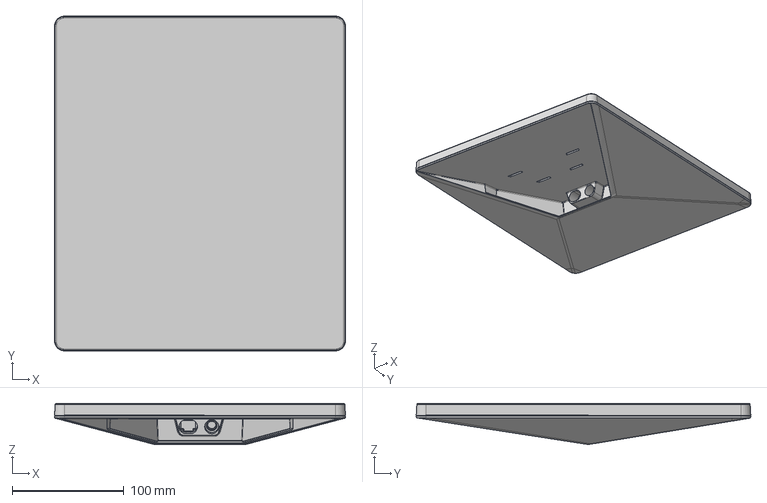
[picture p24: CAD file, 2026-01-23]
reference/Starlink_G4_Mini_Dish.stp
260.0 x 299.0 x 36.7 mm

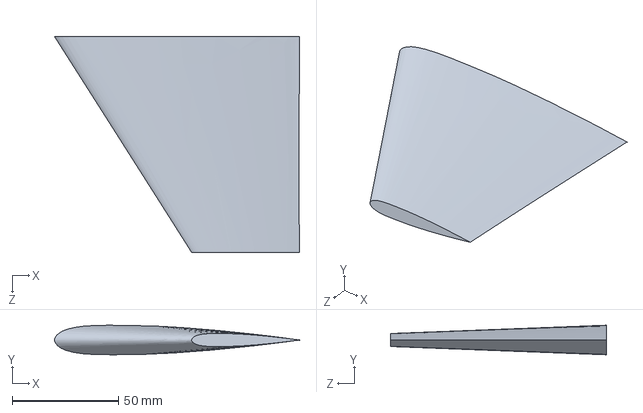
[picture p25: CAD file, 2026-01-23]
reference/Rudder_V1_NACA0012.SLDPRT
115.3 x 13.9 x 101.6 mm

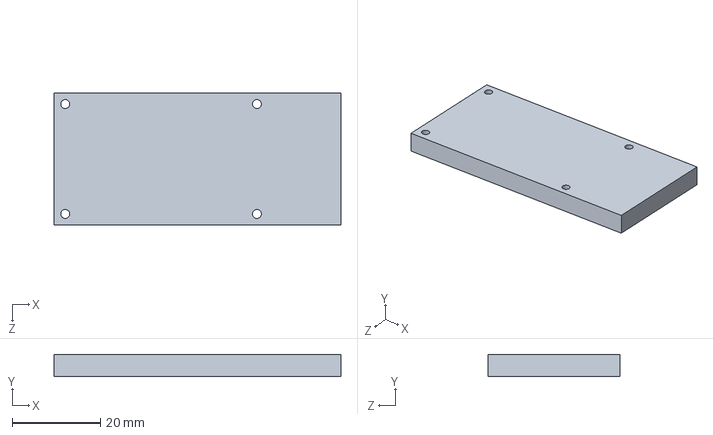
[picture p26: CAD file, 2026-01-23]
reference/Shelf Parts/RaspPi.SLDPRT
65.0 x 5.00 x 30.0 mm

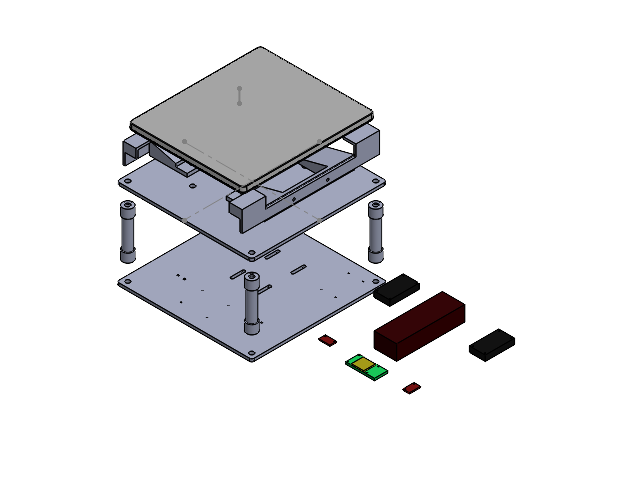
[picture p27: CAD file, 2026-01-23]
reference/Assemblies/ShelfAssemFinal.SLDASM
BottomShelf3.1
GPS
IMU x 2
LiPOBatt
RaspPi
ShelfSupportEndCaps x 8
Starlink Mini stand part A
Starlink Mini stand part B 1.2
Starlink_G4_Mini_Dish
StepDownConverter x 2
SupportColumns x 4

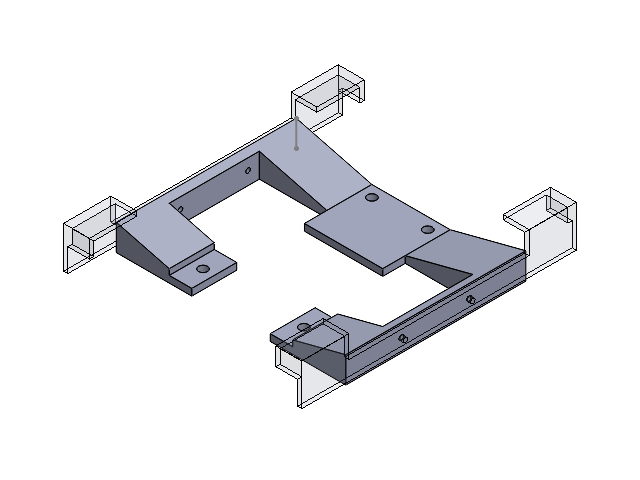
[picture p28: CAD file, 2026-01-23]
reference/Assemblies/Starlink Mount Assem.SLDASM
Starlink Mini stand part A
Starlink Mini stand part B 1.2

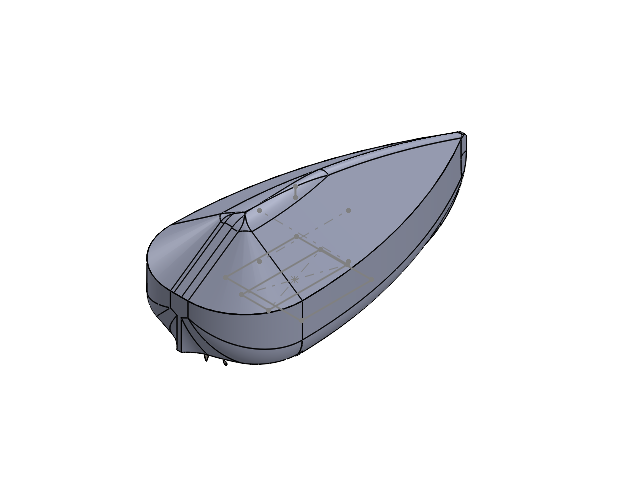
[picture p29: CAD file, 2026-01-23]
reference/Assemblies/BoatWithElectronics.SLDASM
BottomShell2.2
TopShell1.2
Propeller
BottomShelf3.1
GPS
IMU x 2
LiPOBatt
RaspPi
ShelfSupportEndCaps x 8
Starlink Mini stand part A
Starlink Mini stand part B 1.2
Starlink_G4_Mini_Dish
StepDownConverter x 2
SupportColumns x 4
Battery2
Battery3
Part4^BoatWithElectronics

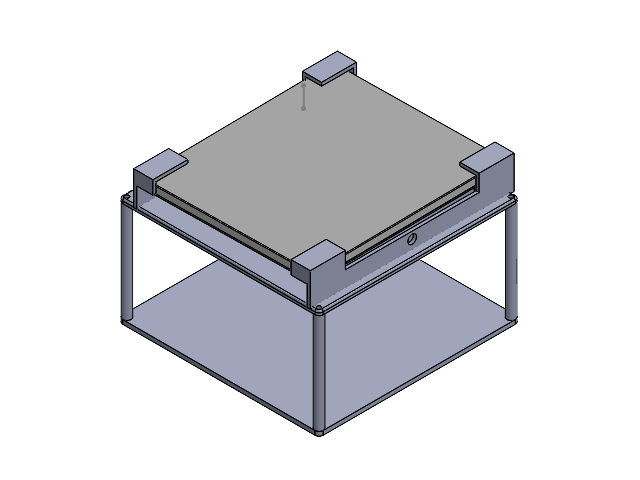
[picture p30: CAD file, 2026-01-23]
reference/Shelves2.0WithStarlinkAndMount.SLDASM
Shelves2.0
Starlink_G4_Mini_Dish

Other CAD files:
reference/Assem2.SLDASM
reference/Shelf Assebmly with components.SLDASM
reference/BottomAssem.SLDASM
reference/92005A452_Steel Pan Head Phillips Screw.SLDDRW
reference/92005A452_Steel Pan Head Phillips Screw.SLDPRT
reference/Aquabot Upper Shelf.SLDPRT
reference/Aquabot lower shelf.SLDPRT
reference/Assem2Drawing.SLDDRW
reference/Assemblies/BoatWithElectronicsDrawing.SLDDRW
reference/Assemblies/HullWithShelves.SLDDRW
reference/Assemblies/ShelfAssemFinalDrawing.SLDDRW
reference/Battery2.SLDPRT
reference/BottomAssem.SLDDRW
reference/BottomShelf3.1.DXF
reference/BottomShelf3.1.SLDDRW
reference/BottomShell2.2.SLDPRT
reference/BottomShell2.2.STL
reference/BottomShell2.2TDPdrwg.SLDDRW
reference/BottomShell2.2_solid.SLDPRT
reference/Lower Shell.SLDDRW
reference/Motor Mock.SLDPRT
reference/Rudder_V1.SLDDRW
reference/Shelf Parts/GPS.SLDPRT
reference/Shelf Parts/IMU.SLDPRT
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

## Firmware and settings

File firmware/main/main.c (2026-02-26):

/**
 * main.c
 *
 * AQUABOTS — ESP32-S3 Swarm Framework for Autonomous Aquatic Drones
 *
 * Entry point for the swarm coordination firmware. Initialises all modules,
 * registers callbacks, starts swarm protocols, and launches the serial console.
 *
 * Module startup order:
 *   1. NVS flash
 *   2. node_config   — loads or provisions persistent node identity
 *   3. swarm_transport — initialises ESP-NOW radio
 *   4. membership    — peer discovery via HELLO broadcasts
 *   5. leader_election — highest node_id election + TDMA beacons
 *   6. scheduler     — TDMA slot management
 *   7. command_engine — GOTO/HOLD/STOP/RESUME distribution
 *   8. formation     — coordinated spatial formation control
 *   9. obstacle_sense — sensor abstraction and swarm-wide scan fusion
 *  10. avoidance     — collision avoidance policy engine
 *
 * If a real A02YYUW ultrasonic sensor is connected, call a02yyuw_init()
 * here before obstacle_sense_start() and register the hardware driver:
 *
 *   #include "a02yyuw.h"
 *   a02yyuw_init(0, UART_NUM_1, GPIO_NUM_17, -1, 0);   // Forward sensor
 *   obstacle_sense_register_driver(a02yyuw_scan_driver);
 *
 * Without that call the system defaults to mock mode, which is fully
 * functional for swarm testing without physical sensors attached.
 */

#include "freertos/FreeRTOS.h"
#include "freertos/task.h"
#include "esp_log.h"
#include "nvs_flash.h"
#include "esp_console.h"
#include <stdlib.h>

#include "node_config.h"
#include "swarm_transport.h"
#include "membership.h"
#include "leader_election.h"
#include "scheduler.h"
#include "command_engine.h"
#include "formation.h"
#include "obstacle_sense.h"
#include "avoidance.h"
/* Uncomment to use real A02YYUW hardware sensor: */
/* #include "a02yyuw.h" */

static const char *TAG = "MAIN";

// ============================================================================
// MEMBERSHIP CALLBACKS
// ============================================================================

static void on_member_joined(const member_info_t *member)
{
    ESP_LOGI(TAG, "*** NEW MEMBER DISCOVERED ***");
    ESP_LOGI(TAG, "    Node ID: %u", member->node_id);
    ESP_LOGI(TAG, "    MAC: %02x:%02x:%02x:%02x:%02x:%02x",
             member->mac[0], member->mac[1], member->mac[2],
             member->mac[3], member->mac[4], member->mac[5]);
    ESP_LOGI(TAG, "    RSSI: %d dBm", member->last_rssi);
}

static void on_member_lost(const member_info_t *member)
{
    ESP_LOGW(TAG, "*** MEMBER LOST (TIMEOUT) ***");
    ESP_LOGW(TAG, "    Node ID: %u", member->node_id);
}

// ============================================================================
// LEADER ELECTION CALLBACKS
// ============================================================================

static void on_leader_changed(uint16_t new_leader_id, bool is_self)
{
    if (is_self) {
        ESP_LOGI(TAG, "*** I AM NOW THE LEADER ***");
        ESP_LOGI(TAG, "    Node ID: %u", new_leader_id);
        ESP_LOGI(TAG, "    Generating TDMA schedule...");
    } else {
        ESP_LOGI(TAG, "*** NEW LEADER ELECTED ***");
        ESP_LOGI(TAG, "    Leader Node ID: %u", new_leader_id);
    }
}

static void on_schedule_updated(const tdma_slot_t *schedule, int num_slots)
{
    ESP_LOGI(TAG, "*** TDMA SCHEDULE UPDATED ***");
    ESP_LOGI(TAG, "    Number of slots: %d", num_slots);

    int my_slot = leader_election_get_my_slot();
    if (my_slot >= 0) {
        ESP_LOGI(TAG, "    My slot: %d (at %d ms)", my_slot, my_slot * 50);
    } else {
        ESP_LOGW(TAG, "    My slot: NOT ASSIGNED");
    }
}

// ============================================================================
// COMMAND ENGINE CALLBACKS
// ============================================================================

static bool on_command_received(const swarm_command_t *command)
{
    ESP_LOGI(TAG, "*** COMMAND RECEIVED ***");
    ESP_LOGI(TAG, "    Type: %s", command_engine_get_type_name(command->cmd_type));
    ESP_LOGI(TAG, "    ID: %lu", (unsigned long)command->cmd_id);
    ESP_LOGI(TAG, "    Target: %u", command->target_node);

    if (command->cmd_type == CMD_GOTO) {
        ESP_LOGI(TAG, "    Waypoint: (%ld, %ld)", (long)command->param1, (long)command->param2);
        ESP_LOGI(TAG, "    Heading: %ld°", (long)command->param3);
    }

    return true;
}

static void on_command_status(const swarm_command_t *command, command_status_t status)
{
    ESP_LOGI(TAG, "*** COMMAND STATUS CHANGE ***");
    ESP_LOGI(TAG, "    Command: %s", command_engine_get_type_name(command->cmd_type));
    ESP_LOGI(TAG, "    Status: %s", command_engine_get_status_name(status));
}

// ============================================================================
// FORMATION CALLBACKS
// ============================================================================

static void on_formation_changed(const formation_config_t *config)
{
    ESP_LOGI(TAG, "*** FORMATION CHANGED ***");
    ESP_LOGI(TAG, "    Type: %s", formation_type_to_string(config->type));
    ESP_LOGI(TAG, "    Nodes: %d", config->node_count);
    ESP_LOGI(TAG, "    Spacing: %ld mm", (long)config->spacing_mm);
    ESP_LOGI(TAG, "    Center: (%ld, %ld) mm",
             (long)config->center_x_mm, (long)config->center_y_mm);
}

static void on_position_assigned(const formation_position_t *position, int node_index)
{
    ESP_LOGI(TAG, "*** POSITION ASSIGNED ***");
    ESP_LOGI(TAG, "    Formation index: %d%s",
             node_index, node_index == 0 ? " (leader)" : "");
    ESP_LOGI(TAG, "    Offset: (%ld, %ld) mm",
             (long)position->x_mm, (long)position->y_mm);
    ESP_LOGI(TAG, "    Heading offset: %d°", position->heading_deg);
}

// ============================================================================
// OBSTACLE SENSING CALLBACKS
// ============================================================================

static void on_obstacle_scan(const obstacle_scan_t *scan)
{
    if (scan->num_detections > 0) {
        ESP_LOGI(TAG, "*** LOCAL SCAN: %d obstacle(s) ***", scan->num_detections);
        for (int i = 0; i < scan->num_detections && i < 3; i++) {
            ESP_LOGI(TAG, "    [%d] %d mm @ %d°",
                     i, scan->detections[i].range_mm, scan->detections[i].bearing_deg);
        }
    }
}

static void on_remote_obstacle(uint16_t node_id, const obstacle_scan_t *scan)
{
    if (scan->num_detections > 0) {
        ESP_LOGI(TAG, "*** REMOTE SCAN from node %u: %d obstacle(s) ***",
                 node_id, scan->num_detections);
    }
}

// ============================================================================
// AVOIDANCE CALLBACKS
// ============================================================================

static void on_avoidance_state_changed(avoidance_state_t new_state,
                                       const obstacle_detection_t *closest)
{
    switch (new_state) {
        case AVOIDANCE_STATE_CLEAR:
            ESP_LOGI(TAG, "*** AVOIDANCE: path clear ***");
            break;
        case AVOIDANCE_STATE_WARNING:
            if (closest) {
                ESP_LOGW(TAG, "*** AVOIDANCE WARNING: obstacle at %d mm @ %d° ***",
                         closest->range_mm, closest->bearing_deg);
            }
            break;
        case AVOIDANCE_STATE_DANGER:
            if (closest) {
                ESP_LOGE(TAG, "*** AVOIDANCE DANGER: obstacle at %d mm @ %d° — taking action ***",
                         closest->range_mm, closest->bearing_deg);
            }
            break;
        case AVOIDANCE_STATE_DISABLED:
            break;
    }
}

static void on_avoidance_suggest(int16_t bearing_deg, int16_t range_clear_mm)
{
    ESP_LOGI(TAG, "*** AVOIDANCE: suggested alternate bearing %d° (clear to %d mm) ***",
             bearing_deg, range_clear_mm);
}

// ============================================================================
// CONSOLE COMMANDS
// ============================================================================

static int cmd_members(int argc, char **argv)
{
    membership_print_table();
    return 0;
}

static int cmd_leader(int argc, char **argv)
{
    uint16_t leader_id = leader_election_get_leader();
    bool is_leader     = leader_election_is_leader();

    printf("\n=== Leader Information ===\n");
    if (leader_id == 0) {
        printf("Leader: NONE (election pending)\n");
    } else {
        printf("Leader Node ID: %u\n", leader_id);
        printf("I am leader: %s\n", is_leader ? "YES" : "NO");
    }

    leader_state_t state = leader_election_get_state();
    const char *state_str;
    switch (state) {
        case LEADER_STATE_FOLLOWER:  state_str = "FOLLOWER";  break;
        case LEADER_STATE_CANDIDATE: state_str = "CANDIDATE"; break;
        case LEADER_STATE_LEADER:    state_str = "LEADER";    break;
        default:                     state_str = "UNKNOWN";   break;
    }
    printf("State: %s\n\n", state_str);
    return 0;
}

static int cmd_schedule(int argc, char **argv)
{
    tdma_slot_t schedule[TDMA_MAX_SLOTS];
    int num_slots = leader_election_get_schedule(schedule, TDMA_MAX_SLOTS);

    printf("\n=== TDMA Schedule (%d slots) ===\n", num_slots);
    if (num_slots == 0) {
        printf("No schedule available yet.\n\n");
        return 0;
    }

    printf("%-8s %-10s %-15s\n", "Slot", "Node ID", "Time (ms)");
    printf("--------------------------------------------\n");

    int my_slot = leader_election_get_my_slot();
    for (int i = 0; i < num_slots; i++) {
        if (schedule[i].active) {
            const char *marker = (i == my_slot) ? " <-- ME" : "";
            printf("%-8d %-10u %-15d%s\n",
                   i, schedule[i].node_id, i * TDMA_SLOT_DURATION_MS, marker);
        }
    }

    printf("\n");
    if (my_slot >= 0) {
        printf("My slot: %d  |  Time to slot: %d ms\n\n",
               my_slot, leader_election_get_time_to_slot());
    } else {
        printf("My slot: NOT ASSIGNED\n\n");
    }
    return 0;
}

static int cmd_goto(int argc, char **argv)
{
    if (argc < 3 || argc > 4) {
        printf("Usage: goto <x> <y> [heading]\n");
        printf("  x, y: target position (metres)\n");
        printf("  heading: target heading in degrees (default 0)\n");
        return 1;
    }

    int32_t x       = atoi(argv[1]);
    int32_t y       = atoi(argv[2]);
    int32_t heading = (argc >= 4) ? atoi(argv[3]) : 0;

    printf("Sending GOTO (%ld, %ld) heading %ld°\n",
           (long)x, (long)y, (long)heading);

    esp_err_t err = command_engine_send_command(CMD_GOTO, 0, x, y, heading);
    if (err == ESP_OK) {
        printf("Command sent to swarm\n");
    } else {
        printf("Failed: %s\n", esp_err_to_name(err));
        if (err == ESP_ERR_INVALID_STATE) {
            printf("(Only the leader can send commands)\n");
        }
    }
    return 0;
}

static int cmd_hold(int argc, char **argv)
{
    esp_err_t err = command_engine_send_command(CMD_HOLD, 0, 0, 0, 0);
    printf("HOLD: %s\n", err == ESP_OK ? "sent" : esp_err_to_name(err));
    if (err == ESP_ERR_INVALID_STATE) {
        printf("(Only the leader can send commands)\n");
    }
    return 0;
}

static int cmd_stop(int argc, char **argv)
{
    esp_err_t err = command_engine_send_command(CMD_STOP, 0, 0, 0, 0);
    printf("STOP: %s\n", err == ESP_OK ? "sent" : esp_err_to_name(err));
    if (err == ESP_ERR_INVALID_STATE) {
        printf("(Only the leader can send commands)\n");
    }
    return 0;
}

static int cmd_resume(int argc, char **argv)
{
    esp_err_t err = command_engine_send_command(CMD_RESUME, 0, 0, 0, 0);
    printf("RESUME: %s\n", err == ESP_OK ? "sent" : esp_err_to_name(err));
    if (err == ESP_ERR_INVALID_STATE) {
        printf("(Only the leader can send commands)\n");
    }
    return 0;
}

static int cmd_status(int argc, char **argv)
{
    command_state_t state;

    printf("\n=== Command Status ===\n");
    if (!command_engine_get_state(&state)) {
        printf("Status: IDLE (no active command)\n\n");
        return 0;
    }

    printf("Command:  %s\n", command_engine_get_type_name(state.command.cmd_type));
    printf("Status:   %s\n", command_engine_get_status_name(state.status));
    printf("ID:       %lu\n", (unsigned long)state.command.cmd_id);

    if (state.command.cmd_type == CMD_GOTO) {
        printf("Target:   (%ld, %ld)\n",
               (long)state.command.param1, (long)state.command.param2);
        printf("Heading:  %ld°\n", (long)state.command.param3);
    }

    uint32_t elapsed = esp_log_timestamp() - state.start_time_ms;
    printf("Elapsed:  %lu ms\n", (unsigned long)elapsed);
    printf("\n");
    return 0;
}

static void register_console_commands(void)
{
    const esp_console_cmd_t cmds[] = {
        { "members",  "Show discovered swarm members",           NULL, &cmd_members  },
        { "leader",   "Show leader information",                 NULL, &cmd_leader   },
        { "schedule", "Show TDMA schedule",                      NULL, &cmd_schedule },
        { "goto",     "Send GOTO command (leader only)",         NULL, &cmd_goto     },
        { "hold",     "Send HOLD command (leader only)",         NULL, &cmd_hold     },
        { "stop",     "Send STOP command (leader only)",         NULL, &cmd_stop     },
        { "resume",   "Send RESUME command (leader only)",       NULL, &cmd_resume   },
        { "status",   "Show current command status",             NULL, &cmd_status   },
    };

    for (int i = 0; i < (int)(sizeof(cmds) / sizeof(cmds[0])); i++) {
        esp_console_cmd_register(&cmds[i]);
    }

    formation_register_commands();
    obstacle_sense_register_commands();
    avoidance_register_commands();
}

// ============================================================================
// MAIN
// ============================================================================

void app_main(void)
{
    ESP_LOGI(TAG, "================================================");
    ESP_LOGI(TAG, " AQUABOTS — ESP32-S3 Swarm Framework");
    ESP_LOGI(TAG, "================================================");

    /* Initialize NVS (required by node_config and WiFi). */
    esp_err_t ret = nvs_flash_init();
    if (ret == ESP_ERR_NVS_NO_FREE_PAGES || ret == ESP_ERR_NVS_NEW_VERSION_FOUND) {
        ESP_ERROR_CHECK(nvs_flash_erase());
        ret = nvs_flash_init();
    }
    ESP_ERROR_CHECK(ret);

    /* Load or provision node identity. */
    node_config_init();

    uint16_t my_node_id = node_config_get_node_id();
    uint8_t  my_mac[6];
    node_config_get_mac(my_mac);

    ESP_LOGI(TAG, "------------------------------------------------");
    if (node_config_is_provisioned()) {
        ESP_LOGI(TAG, "Node ID : %u", my_node_id);
    } else {
        ESP_LOGI(TAG, "Node ID : NOT PROVISIONED");
        ESP_LOGI(TAG, "Use console: set_node_id <id>");
    }
    ESP_LOGI(TAG, "MAC     : %02x:%02x:%02x:%02x:%02x:%02x",
             my_mac[0], my_mac[1], my_mac[2],
             my_mac[3], my_mac[4], my_mac[5]);
    ESP_LOGI(TAG, "------------------------------------------------");

    /* Bring up ESP-NOW radio. */
    swarm_transport_init();

    /* Initialise all swarm modules. */
    membership_init();
    leader_election_init();
    scheduler_init();
    command_engine_init();
    formation_init();
    obstacle_sense_init();
    avoidance_init();

    ESP_LOGI(TAG, "All modules initialised");

    /* Start serial provisioning console. */
    node_config_start_console();
    register_console_commands();

    if (!node_config_is_provisioned()) {
        ESP_LOGW(TAG, "=== NODE NOT PROVISIONED ===");
        ESP_LOGW(TAG, "Console only mode. Use 'set_node_id <id>' then restart.");
        return;
    }

    /* --- Optional: register real A02YYUW sensor here --- *
     * #include "a02yyuw.h"
     * a02yyuw_init(0, UART_NUM_1, GPIO_NUM_17, -1, 0);
     * obstacle_sense_register_driver(a02yyuw_scan_driver);
     * obstacle_sense_configure(4500, 120);
     * ---------------------------------------------------- */

    /* Register event callbacks. */
    membership_register_joined_cb(on_member_joined);
    membership_register_lost_cb(on_member_lost);
    leader_election_register_leader_changed_cb(on_leader_changed);
    leader_election_register_schedule_updated_cb(on_schedule_updated);
    command_engine_register_received_cb(on_command_received);
    command_engine_register_status_cb(on_command_status);
    formation_register_changed_cb(on_formation_changed);
    formation_register_position_cb(on_position_assigned);
    obstacle_sense_register_scan_cb(on_obstacle_scan);
    obstacle_sense_register_remote_cb(on_remote_obstacle);
    avoidance_register_state_cb(on_avoidance_state_changed);
    avoidance_register_suggest_cb(on_avoidance_suggest);

    /* Start all swarm protocols. */
    ESP_LOGI(TAG, "=== STARTING SWARM PROTOCOLS ===");
    membership_start();
    leader_election_start();
    command_engine_start();
    formation_start();
    obstacle_sense_start();
    avoidance_start();

    ESP_LOGI(TAG, "System running.");
    ESP_LOGI(TAG, "Console: help | info | members | leader | schedule |");
    ESP_LOGI(TAG, "         goto | hold | stop | resume | status |");
    ESP_LOGI(TAG, "         formation | spacing | fmove | fstatus |");
    ESP_LOGI(TAG, "         sensors | detections | mock_add | mock_clear | path_check |");
    ESP_LOGI(TAG, "         avoid_status | avoid_enable | avoid_disable | avoid_config");
}

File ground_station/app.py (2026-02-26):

# -*- coding: utf-8 -*-
"""
app.py — Flask web server for the AquaBot ground station dashboard.

Serves the operator dashboard (HTML/CSS/JS), runs the iPerf3 network
performance test, provides a /api/data endpoint for live sensor and
telemetry data, and starts the serial bridge and MQTT client at launch.
"""

import subprocess
import json
import logging

from flask import Flask, render_template, jsonify

import config
import serial_bridge
import mqtt_client

logging.basicConfig(level=logging.INFO,
                    format="%(asctime)s %(name)s %(levelname)s %(message)s")

app = Flask(__name__, template_folder="templates", static_folder="static")
app.config['TEMPLATES_AUTO_RELOAD'] = True


# ---------------------------------------------------------------------------
# Home page
# ---------------------------------------------------------------------------

@app.route('/')
def index():
    # Pass the signaling URL so webrtc.js can connect without hardcoding.
    # Set AQUABOT_SIGNALING_CLIENT_HOST to the Jetson's LAN IP before launch.
    return render_template('index.html',
                           signaling_url=config.SIGNALING_URL)


# ---------------------------------------------------------------------------
# Live telemetry API  (polled by telemetry.js every 2 s)
# ---------------------------------------------------------------------------

@app.route('/api/data')
def api_data():
    """
    Return the latest sensor, telemetry, and obstacle data as JSON.
    All values are None / null if the serial bridge has not yet received them.
    """
    return jsonify(serial_bridge.get_state())


# ---------------------------------------------------------------------------
# iPerf3 network performance test
# ---------------------------------------------------------------------------

@app.route('/run_iperf')
def run_iperf():
    try:
        result = subprocess.run(
            ["iperf3", "-c", config.IPERF_HOST, "-p", str(config.IPERF_PORT), "--json"],
            capture_output=True,
            text=True,
            timeout=20,
        )

        if not result.stdout.strip():
            raise ValueError("No output from iPerf3")

        data = json.loads(result.stdout)
        end  = data.get("end", {})

        stats = {
            "upload":   round(end.get("sum_sent",     {}).get("bits_per_second", 0) / 1e6, 2),
            "download": round(end.get("sum_received", {}).get("bits_per_second", 0) / 1e6, 2),
            "latency":  round(end.get("streams", [{}])[0].get("sender", {}).get("mean_rtt", 0) / 1000, 2),
            "jitter":   round(end.get("sum", {}).get("jitter_ms",    0), 2),
            "loss":     round(end.get("sum", {}).get("lost_percent", 0), 2),
        }

        return jsonify(stats)

    except Exception as exc:
        return jsonify({"error": str(exc)})


# ---------------------------------------------------------------------------
# Entry point
# ---------------------------------------------------------------------------

if __name__ == "__main__":
    # Start the ESP32-S3 serial bridge (IF-3) — reads telemetry from swarm
    serial_bridge.start()

    # Start the MQTT cloud telemetry client (IF-4 / IF-5) via Starlink
    mqtt_client.start()

    app.run(host=config.FLASK_HOST, port=config.FLASK_PORT)

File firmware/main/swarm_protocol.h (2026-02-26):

/**
 * swarm_protocol.h
 *
 * Swarm packet format definitions and protocol constants.
 */

#ifndef SWARM_PROTOCOL_H
#define SWARM_PROTOCOL_H

#include <stdint.h>
#include <stdbool.h>

// ============================================================================
// PROTOCOL CONSTANTS
// ============================================================================

#define SWARM_MAX_PAYLOAD_SIZE  200  // ESP-NOW limit is ~250, leave room for header
#define SWARM_MAX_NODES         50
#define SWARM_BROADCAST_ADDR    0xFFFF

// ============================================================================
// MESSAGE TYPES
// ============================================================================

typedef enum {
    MSG_TYPE_PING      = 0,  // Demo ping
    MSG_TYPE_ACK       = 1,  // Demo ack
    MSG_TYPE_HELLO     = 2,  // Membership discovery
    MSG_TYPE_BEACON    = 3,  // TDMA schedule
    MSG_TYPE_COMMAND   = 4,  // Swarm command
    MSG_TYPE_FORMATION = 5,  // Formation plan
    MSG_TYPE_TELEMETRY = 6,  // Status updates
    MSG_TYPE_OBSTACLE  = 7,  // Obstacle scan broadcast
} msg_type_t;

// ============================================================================
// SWARM PACKET HEADER
// ============================================================================

typedef struct __attribute__((packed)) {
    uint16_t swarm_id;      // Swarm identifier
    uint16_t src_id;        // Source node_id
    uint16_t dst_id;        // Destination (node_id or SWARM_BROADCAST_ADDR)
    uint8_t group_id;       // Group identifier (0 = all)
    uint8_t msg_type;       // Message type (msg_type_t)
    uint16_t seq;           // Sequence number
    uint8_t flags;          // Protocol flags
    uint8_t payload_len;    // Payload length in bytes
    // Payload follows
} swarm_header_t;

// ============================================================================
// DEMO PACKET (ping/ack format)
// ============================================================================

typedef struct __attribute__((packed)) {
    uint8_t msg_type;      // 0=PING, 1=ACK
    uint32_t counter;      // Message sequence number
    uint32_t t_ms;         // Timestamp in milliseconds
    char text[16];         // Optional text field
} demo_msg_t;

#endif // SWARM_PROTOCOL_H

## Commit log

2026-01-23 Moved all files to PREVIOUS TEAM directory
    [92005A452_Steel Pan Head Phillips Screw.SLDDRW, 92005A452_Steel Pan Head Phillips Screw.SLDPRT, Aquabot Upper Shelf.SLDPRT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]
2026-01-31 esp32 setup
2026-01-31 send / receive logic for esp32s. test 2
2026-02-01 git commit -m "feat: NVS node provisioning + serial console
    Single binary deployment with runtime identity.
    Node ID persists across reboots. Console commands work.
    Ready for Step 3 membership discovery."
    [main.c]
2026-02-26 Reorganize repo and add ground station integration layer
    Repo restructure:
    - firmware/ (was John/Firmware/swarmLogic/)
    - ground_station/ (was Mayra/gui/)
    - docs/ (was ProjectContextFiles/ + John/Pics/)
    - reference/ (was PREVIOUS TEAM/)
    - Removed all empty placeholder folders (AME, Alex, COMMUNICATIONS, Jamie,
    Kama, NAVIGATION, POWER, Robert, SENSORS, SOFTWARE) and all Desktop.ini /
    empty.txt placeholder files
    - Deleted step7/ backup and handoff doc artifacts
    - Renamed ground_station/Static/ -> static/ (case fix for Linux/Jetson)
    Ground station integration (IF-3, IF-4/IF-5):
    - config.py — centralized config; all IPs/ports/serial settings are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
    [92005A452_Steel Pan Head Phillips Screw.SLDDRW, 92005A452_Steel Pan Head Phillips Screw.SLDPRT, Aquabot Upper Shelf.SLDPRT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]
2026-02-26 Add Mayra_original/ — unmodified copy of dashboard for review
